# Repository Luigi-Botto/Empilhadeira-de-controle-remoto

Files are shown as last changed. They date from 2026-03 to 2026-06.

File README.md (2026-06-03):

# Carrinho de Controle Remoto BLE - Raspberry Pi Pico
Luigi Lauand Botto - 23.01066-5
Luigi de Menezes Collesi - 23.00625-0
Enzo Pistori Fontenelle de Oliveira - 23.00768-5

Este repositório contém os arquivos de hardware, firmware e documentação técnica para o desenvolvimento de um carrinho de controle remoto controlado via smartphone, projetado como parte da disciplina de Microcontroladores. O sistema utiliza o microcontrolador **Raspberry Pi Pico**, comunicação via **Bluetooth Low Energy (BLE)** e uma estrutura robusta montada sobre um chassi de **MDF** com placas de circuito impresso (PCI) customizadas.

---

## 📋 Sumário
1. [Visão Geral do Projeto](#-visão-geral-do-projeto)
2. [Arquitetura do Sistema](#-arquitetura-do-sistema)
3. [Especificações de Hardware](#-especificações-de-hardware)
4. [Mapeamento de Pinos (GPIO)](#-mapeamento-de-pinos-gpio)
5. [Evolução do Design Mecânico e PCI](#-evolução-do-design-mecânico-e-pci)
6. [Firmware e Protocolo de Comunicação](#-firmware-e-protocolo-de-comunicação)
7. [Estrutura do Repositório](#-estrutura-do-repositório)
8. [Orçamento do Projeto](#-orçamento-do-projeto)
9. [Como Executar o Projeto](#-como-executar-o-projeto)

---

## 🔍 Visão Geral do Projeto
O objetivo do projeto consiste na construção de um veículo terrestre de quatro rodas motrizes controlado remotamente através de um dispositivo móvel com sistema operacional **iOS**. 

A interface sem fio é estabelecida por meio do módulo Bluetooth BLE **HC-08**, responsável por realizar a ponte de comunicação entre o smartphone e o Raspberry Pi Pico. No ambiente iOS, é utilizado o aplicativo **BlackBLE** da RoboCore (adquirido por R$ 4,90), configurado para transmitir pacotes de dados baseados em caracteres simples em letras maiúsculas para o acionamento de direções e periféricos.

---

## 🛠 Arquitetura do Sistema
O fluxo elétrico e de sinais do protótipo segue uma topologia planejada para garantir níveis estáveis de tensão e proteção das portas lógicas do microcontrolador. Uma representação visual completa dessa estrutura está disponível no arquivo `diagrama_blocos.png` localizado na raiz do repositório.

### Fluxo de Potência e Conversão de Sinais:
1. **Fonte de Alimentação Primária:** O circuito é alimentado por uma bateria de lítio com tensão nominal de **7,2 Volts**.
2. **Regulação Buck (Step-Down):** A tensão da bateria é rebaixada e estabilizada por um conversor regulador **LM2596**, configurado para fornecer uma saída constante de **5V**.
3. **Alimentação da Lógica:** O Raspberry Pi Pico recebe energia de forma direta através do pino **VSYS**, utilizando a linha regulada de 5V vinda do step-down.
4. **Conversão de Nível Lógico:** Devido ao fato de o Raspberry Pi Pico operar nativamente com sinais lógicos de **3,3V** e a ponte H **L298N** requerer sinais de **5V** em suas linhas de controle para garantir o acionamento correto dos transistores, foi integrado um **Conversor de Nível Lógico Bidirecional**. O barramento de alta tensão (*High Voltage* - HV) deste módulo conversor é alimentado pelos 5V provenientes da saída do regulador step-down.

---

## ⚙️ Especificações de Hardware

Abaixo encontra-se a listagem detalhada dos principais componentes que integram o hardware do projeto:

| Componente | Função Principal | Especificação / Observação |
| :--- | :--- | :--- |
| **Raspberry Pi Pico** | Unidade de processamento central | Baseado no chip RP2040, operação a 3,3V |
| **Módulo HC-08** | Módulo de comunicação sem fio | Bluetooth Low Energy (BLE), interface serial UART |
| **Ponte H L298N** | Driver de potência para motores | Controle de até 2 canais independentes de corrente |
| **Motores DC (x4)** | Atuadores de tração mecânica | Ligados em paralelo (2 por canal da Ponte H) por lateral |
| **Conversor de Nível Lógico** | Interfaceamento de tensão de dados | Shifter bidirecional de sinal (3,3V para 5V) |
| **Módulo LM2596** | Regulador de tensão Step-Down | Conversor Buck DC-DC ajustado para saída estável de 5V |
| **Bateria de Lítio** | Armazenamento de energia | Tensão de operação de 7,2V |
| **LEDs de Alto Brilho (x2)** | Sistema de iluminação (Faróis) | Conectados em canais independentes (ON/OFF via app) |
| **Chassi Mecânico** | Estrutura física do veículo | Base em MDF com 3mm de espessura |

---

## 📌 Mapeamento de Pinos (GPIO)

As conexões físicas foram estruturadas no circuito impresso e inicializadas no firmware conforme o mapeamento a seguir:

| Periférico / Linha | Função do Pino | Pino no Raspberry Pi Pico | Configuração Digital | Detalhes Técnicos |
| :--- | :--- | :--- | :--- | :--- |
| **Interface UART0 (HC-08)** | Transmissão de Dados (TX) | **GPIO 16** | Saída (`Pin.OUT`) | Conectado diretamente ao RX do HC-08 |
| **Interface UART0 (HC-08)** | Recepção de Dados (RX) | **GPIO 17** | Entrada com Pull-Up (`Pin.IN, Pin.PULL_UP`) | Monitora dados vindos do TX do HC-08 |
| **Ponte H (Lado Esquerdo)** | Motor 1 - Terminal A | **GPIO 2** | Saída (`Pin.OUT`) | Sinal condicionado no Shifter para 5V |
| **Ponte H (Lado Esquerdo)** | Motor 1 - Terminal B | **GPIO 3** | Saída (`Pin.OUT`) | Sinal condicionado no Shifter para 5V |
| **Ponte H (Lado Direito)** | Motor 2 - Terminal A | **GPIO 4** | Saída (`Pin.OUT`) | Sinal condicionado no Shifter para 5V |
| **Ponte H (Lado Direito)** | Motor 2 - Terminal B | **GPIO 5** | Saída (`Pin.OUT`) | Sinal condicionado no Shifter para 5V |
| **Farol Esquerdo (D1)** | Acionamento do LED | **GPIO 28** | Saída (`Pin.OUT`) | Estado lógico controlado via comando BLE |
| **Farol Direito (D2)** | Acionamento do LED | **GPIO 27** | Saída (`Pin.OUT`) | Estado lógico controlado via comando BLE |

---

## 📐 Evolução do Design Mecânico e PCI

### Transição do Sistema de Esterço (Nota de Projeto)
O escopo inicial de engenharia contemplava um mecanismo de direção nas rodas dianteiras baseado no acionamento por um servo motor **MG996R**. A Placa de Circuito Impresso (PCI) foi desenvolvida, impressa e finalizada prevendo as trilhas de dados e alimentação dedicadas a este atuador.

Entretanto, nos ensaios mecânicos de integração, a geometria de esterço projetada apresentou falhas estruturais e travamentos na base de MDF. Como solução de contorno, a equipe optou pela substituição do modelo mecânico tradicional por uma configuração de **direção diferencial (skid-steer / tipo tanque)** utilizando quatro rodas motorizadas.

### Lógica de Curvas e Disposição dos Motores:
* **Conexão Mecânica:** Embora a ponte H L298N possua saídas de potência nominais para apenas dois motores, os quatro motores foram associados em pares paralelos. Os motores de uma mesma lateral pertencem ao mesmo canal de saída da ponte H (e não ao mesmo eixo transversal), permitindo o movimento conjunto de cada lado do veículo.
* **Operação de Curvas:** As manobras são feitas invertendo o sentido de rotação relativo entre as laterais:
  * **Giro à Esquerda:** Lateral direita movimenta-se para frente enquanto a lateral esquerda movimenta-se para trás.
  * **Giro à Direita:** Lateral esquerda movimenta-se para frente enquanto a lateral direita movimenta-se para trás.

*Nota de Design:* O circuito impresso finalizado (PCI) mantém as trilhas e o footprint originais destinados ao servo motor MG996R. Essa característica foi preservada como histórico de desenvolvimento e viabilidade de upgrades mecânicos futuros.

---

## 💻 Firmware e Protocolo de Comunicação

O ambiente lógico do sistema foi desenvolvido sob a linguagem **MicroPython**, utilizando o software **Thonny IDE** para gravação e depuração direta no microcontrolador.

### Protocolo Serial BLE:
A comunicação por Bluetooth baseia-se na escuta constante do barramento `UART(0)`. O aplicativo móvel *BlackBLE* envia strings contendo caracteres simples em **letras maiúsculas** de forma imediata à interação do usuário. O código realiza a leitura desses caracteres e altera as tabelas de verdade das portas lógicas associadas aos pinos `motor1_a`, `motor1_b`, `motor2_a` e `motor2_b` instantaneamente.

### Funcionamento dos Faróis:
Os dois LEDs de sinalização frontal (conectados às GPIOs 27 e 28) operam sob uma lógica assíncrona de alternância (*Toggle Button*). Um botão ON/OFF dedicado no painel do aplicativo envia os comandos específicos de ativação e desativação, mantendo os faróis ligados ou desligados independentemente do estado de translação dos motores.

---

## 📁 Estrutura do Repositório

* 📄 **`diagrama_blocos.png`**: Imagem esquemática detalhando a arquitetura interna e interconexão de blocos do circuito.
* 📄 **`Design_PCI.png`**: Desenho da placa para impressão.
* 📄 **`Esquematico_eletrico.png`**: Imagem esquemática do circuito no KiCad.
* 📄 **`main.py`** *(ou arquivo de código equivalente)*: Código-fonte em MicroPython que roda diretamente no Raspberry Pi Pico.
* 📄 **`README.md`**: Este arquivo de documentação técnica localizado na raiz do repositório.

---

## 💰 Orçamento do Projeto

Abaixo está a relação de custos dos componentes adquiridos para a montagem do protótipo:

| Componente / Material | Quantidade | Custo Estimado (R$) |
| :--- | :---: | :--- |
| Raspberry Pi Pico | 1 | 30,00 |
| Módulo Bluetooth HC-08 | 1 | 35,00 |
| Kit de Baterias (Pilhas Lítio) | 1 | 50,00 |
| Motores DC | 4 | 30,00 |
| Conversor de Nível Lógico | 1 | 25,00 |
| Ponte H L298N | 1 | 20,00 |
| Módulo Step-Down LM2596 | 1 | 7,50 |
| LEDs de Alto Brilho | 2 | 5,00 |
| Resistores | 2 | 0,20 |
| Placa de Circuito Impresso (PCI) | 1 | *Não determinado* |
| Chassi em MDF (3mm) | 1 | *Não determinado* |
| **Custo Total Parcial** | | **R$ 202,70** |

---

## 🚀 Como Executar o Projeto

1. **Validação da Alimentação:** Antes de conectar as saídas às portas digitais do Pico, verifique com um multímetro se a saída do módulo Step-Down LM2596 está ajustada estritamente para **5V** para não danificar o microcontrolador.
2. **Gravação do Firmware:** Abra a IDE Thonny, carregue o arquivo de código fonte, selecione o interpretador correto para o Raspberry Pi Pico e armazene o script diretamente na memória interna do dispositivo.
3. **Operação e Pareamento:** Inicialize a alimentação do circuito por meio da bateria de 7,2V. Abra o aplicativo **BlackBLE** em seu dispositivo iOS, realize o escaneamento físico e conecte-se ao módulo **HC-08**. Configure os botões gráficos para disparar os caracteres maiúsculos definidos para cada comando.

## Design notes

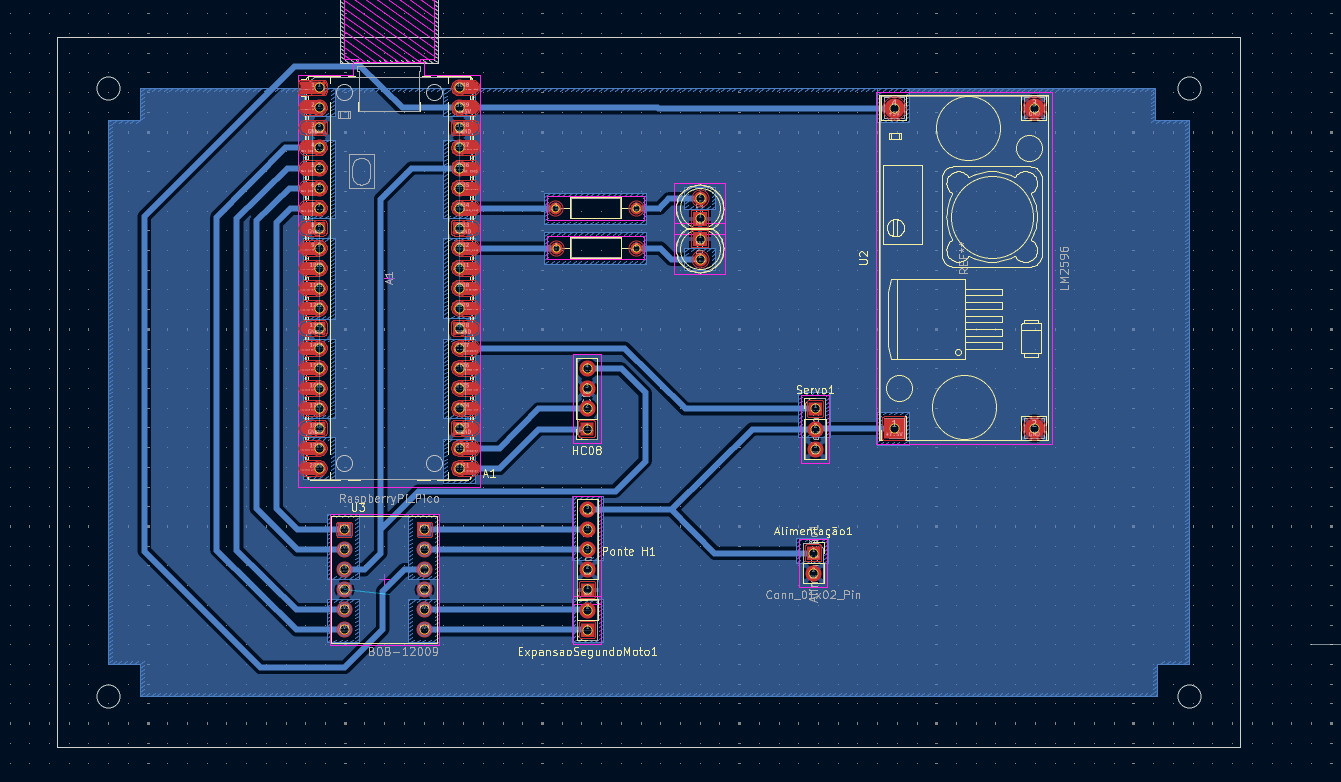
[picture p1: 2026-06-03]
Design_PCI.png

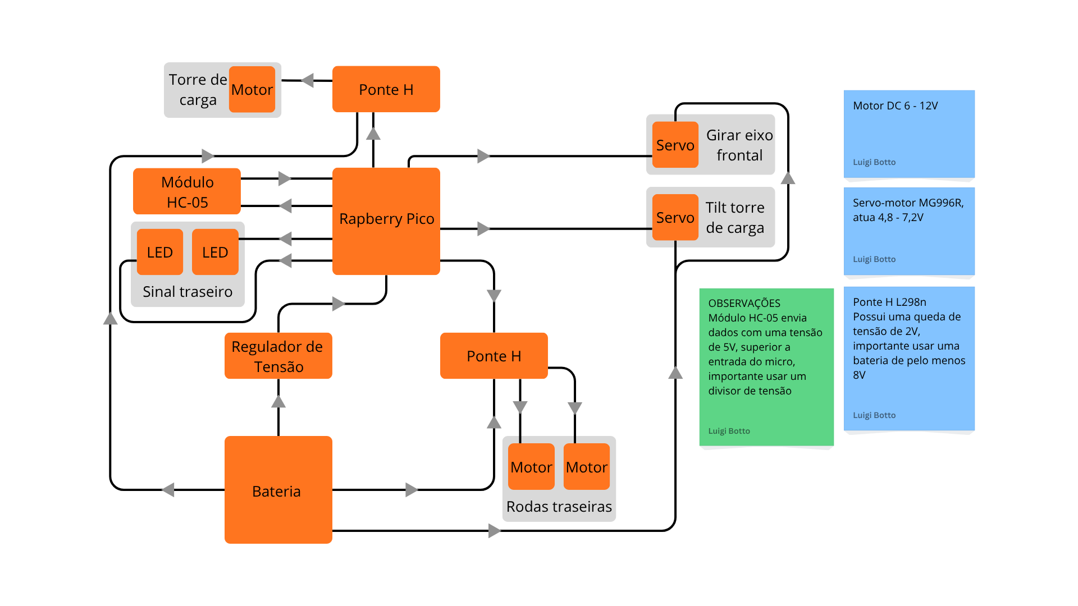
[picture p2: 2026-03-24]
Rapberry Pico.png

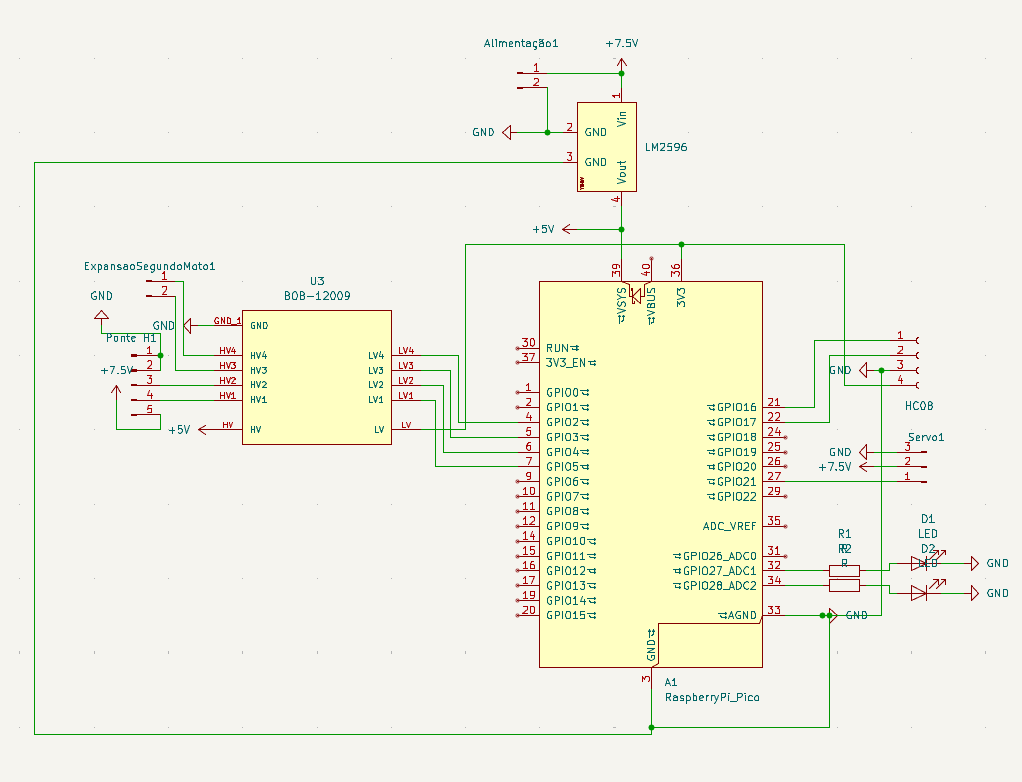
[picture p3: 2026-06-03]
Esquematico.png

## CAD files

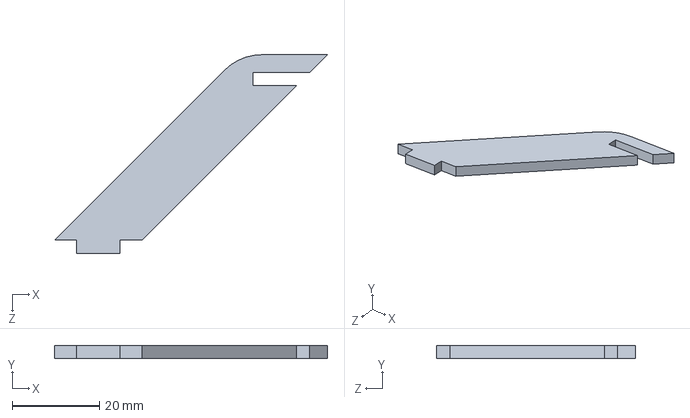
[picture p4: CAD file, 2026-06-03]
Peças/suporte_aero.SLDPRT
62.4 x 3.00 x 45.4 mm

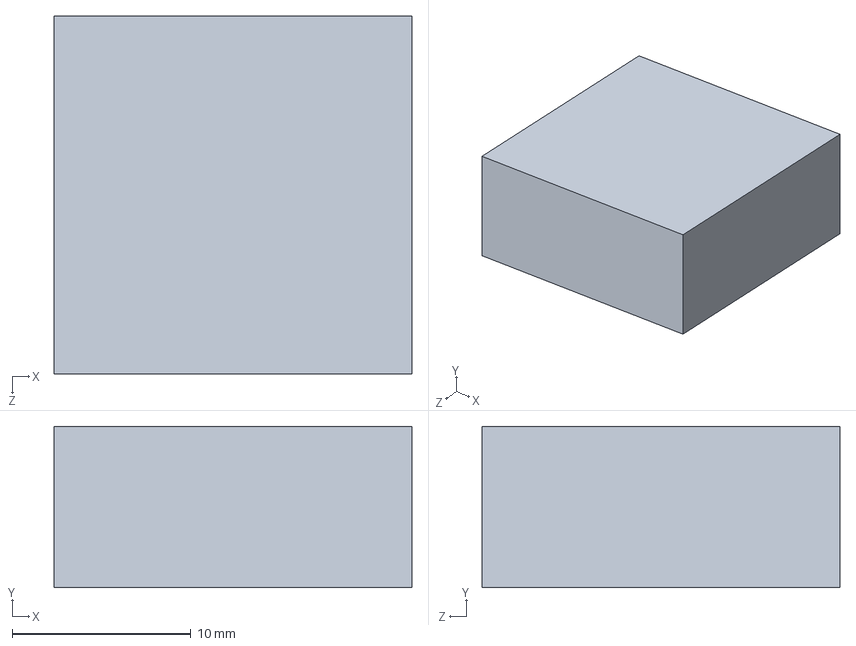
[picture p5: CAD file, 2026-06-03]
Peças/suporte_servo.SLDPRT
20.0 x 9.00 x 20.0 mm

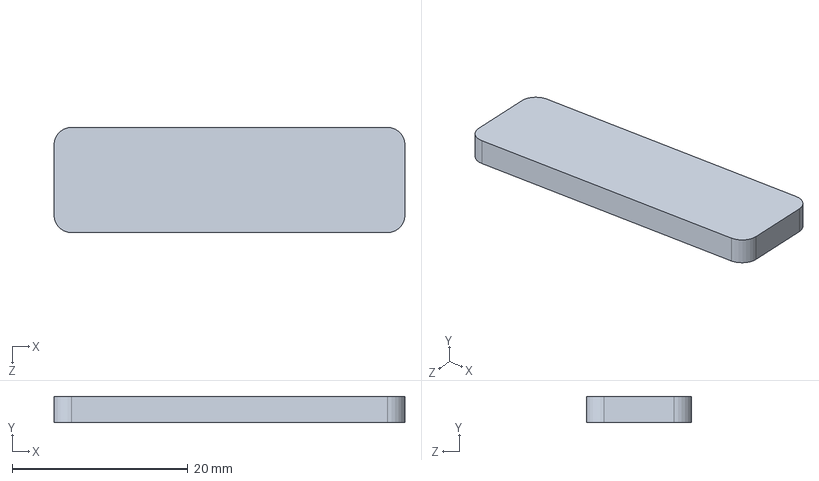
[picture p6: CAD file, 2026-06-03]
Peças/conector_direcao.SLDPRT
40.0 x 3.00 x 12.0 mm

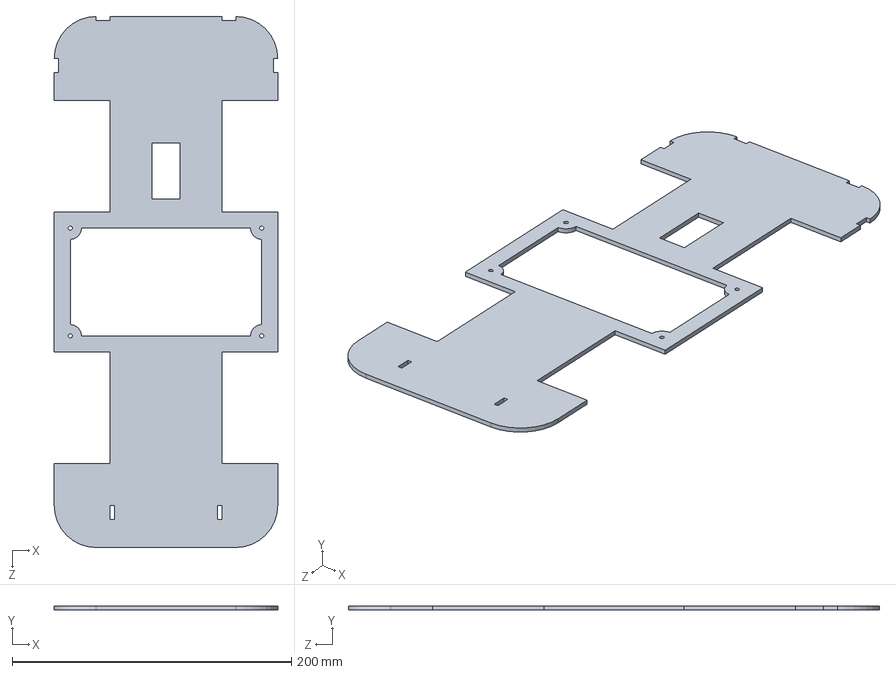
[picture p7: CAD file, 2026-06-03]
Peças/base.SLDPRT
160.0 x 3.00 x 380.0 mm

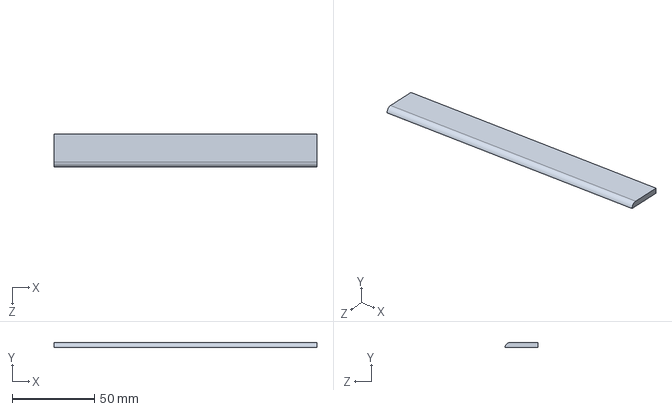
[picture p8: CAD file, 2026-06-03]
Peças/aerofolio.SLDPRT
160.0 x 3.00 x 20.0 mm

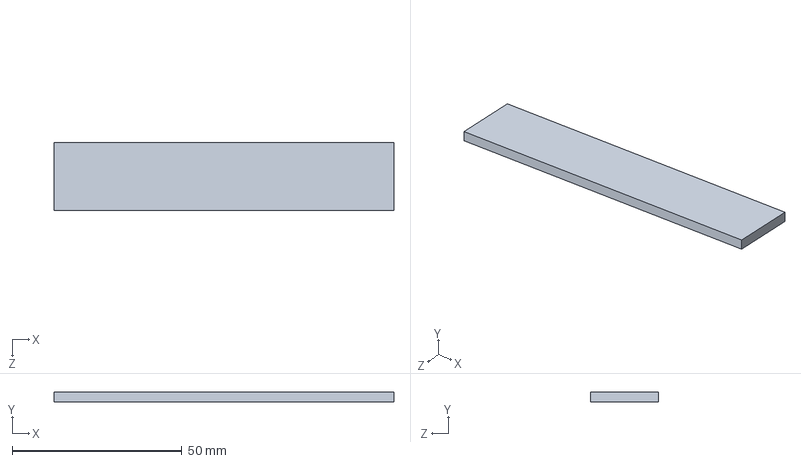
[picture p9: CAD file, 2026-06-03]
Peças/tampo_direcao.SLDPRT
100.0 x 3.00 x 20.0 mm

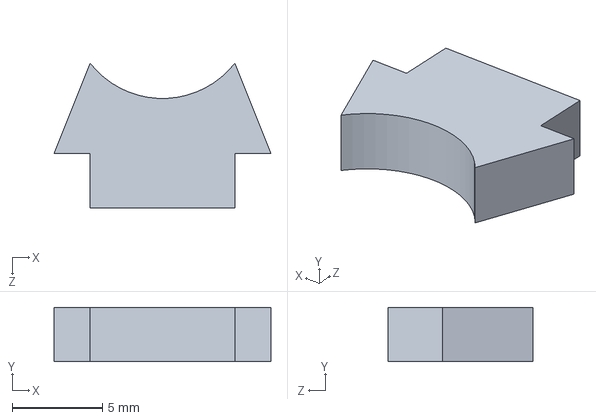
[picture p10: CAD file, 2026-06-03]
Peças/suporte_motor.SLDPRT
12.0 x 3.00 x 8.00 mm

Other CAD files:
Peças/suporte_direcao.SLDPRT
Peças/trilho_direcao.SLDPRT
Peças/aerofolio.DXF
Peças/base.DXF
Peças/conector_direcao.DXF
Peças/suporte_aero.DXF
Peças/suporte_direcao.DXF
Peças/suporte_motor.DXF
Peças/suporte_servo.DXF
Peças/trilho_direcao.DXF

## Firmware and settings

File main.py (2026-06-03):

from machine import UART, Pin
import time

# --- CONFIGURAÇÃO DE HARDWARE ---

# UART0 (Bluetooth HC08) nos pinos GP16 (TX) e GP17 (RX)
uart = UART(0, baudrate=9600, tx=Pin(16), rx=Pin(17, Pin.IN, Pin.PULL_UP))

# Motores (Ponte H nas GPIOs 2, 3, 4 e 5)
# Convencionado: Motor 1 = Lado Esquerdo, Motor 2 = Lado Direito
motor1_a = Pin(2, Pin.OUT)
motor1_b = Pin(3, Pin.OUT)
motor2_a = Pin(4, Pin.OUT)
motor2_b = Pin(5, Pin.OUT)

# LEDs nas portas 27 e 28
led_d2 = Pin(27, Pin.OUT)
led_d1 = Pin(28, Pin.OUT)
led_ligado = False # Variável para controlar o estado (Push ON/OFF)


# --- LOOP PRINCIPAL ---
while True:
    if uart.any():
        dados_recebidos = uart.read()
        
        try:
            # Decodifica e limpa o comando recebido
            comando = dados_recebidos.decode('utf-8').strip()
            # print("Comando recebido:", comando)
            
            # ==========================================
            #   CONTROLE DA TRAÇÃO (FRENTE / TRÁS / PARAR)
            # ==========================================
            if 'Y' in comando:
                # Vai para Frente (Ambos os motores giram para frente)
                motor1_a.value(0)
                motor1_b.value(1)
                motor2_a.value(0)
                motor2_b.value(1)
                
            elif 'A' in comando:
                # Vai para Trás / Ré (Ambos os motores giram para trás)
                motor1_a.value(1)
                motor1_b.value(0)
                motor2_a.value(1)
                motor2_b.value(0)
                
            elif 'U' in comando:
                # Para todos os motores
                motor1_a.value(0)
                motor1_b.value(0)
                motor2_a.value(0)
                motor2_b.value(0)

            # ==========================================
            #   CONTROLE DA DIREÇÃO (DIFERENCIAL DE MOTORES)
            # ==========================================
            elif 'X' in comando:
                # Vira para a Direita: Liga motor esquerdo (1), desliga direito (2)
                motor1_a.value(0)
                motor1_b.value(1)
                motor2_a.value(1)
                motor2_b.value(0)
                
            elif 'B' in comando:
                # Vira para a Esquerda: Liga motor direito (2), desliga esquerdo (1)
                motor1_a.value(1)
                motor1_b.value(0)
                motor2_a.value(0)
                motor2_b.value(1)
                
            elif 'D' in comando:
                # Soltou o botão de curva: Para ambos os motores
                motor1_a.value(0)
                motor1_b.value(0)
                motor2_a.value(0)
                motor2_b.value(0)

            # ==========================================
            #   CONTROLE DOS LEDS (PUSH ON/OFF)
            # ==========================================
            if 'L' in comando:
                # Inverte o estado atual do LED
                led_ligado = not led_ligado
                
                if led_ligado:
                    led_d1.value(1)
                    led_d2.value(1)
                else:
                    led_d1.value(0)
                    led_d2.value(0)

        except Exception as e:
            # Ignora erros de leitura do Bluetooth para não travar o carro
            pass

    # Resposta rápida (20 milissegundos)
    time.sleep(0.02)

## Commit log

2026-03-24 Primeiro commit: Diagrama de blocos
2026-06-03 Documentação
    [Esquematico_eletrico.kicad_pcb, Esquematico_eletrico.kicad_sch, aerofolio.DXF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]
